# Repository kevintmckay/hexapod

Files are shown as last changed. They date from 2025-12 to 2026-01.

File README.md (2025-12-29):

# Hexapod Robot

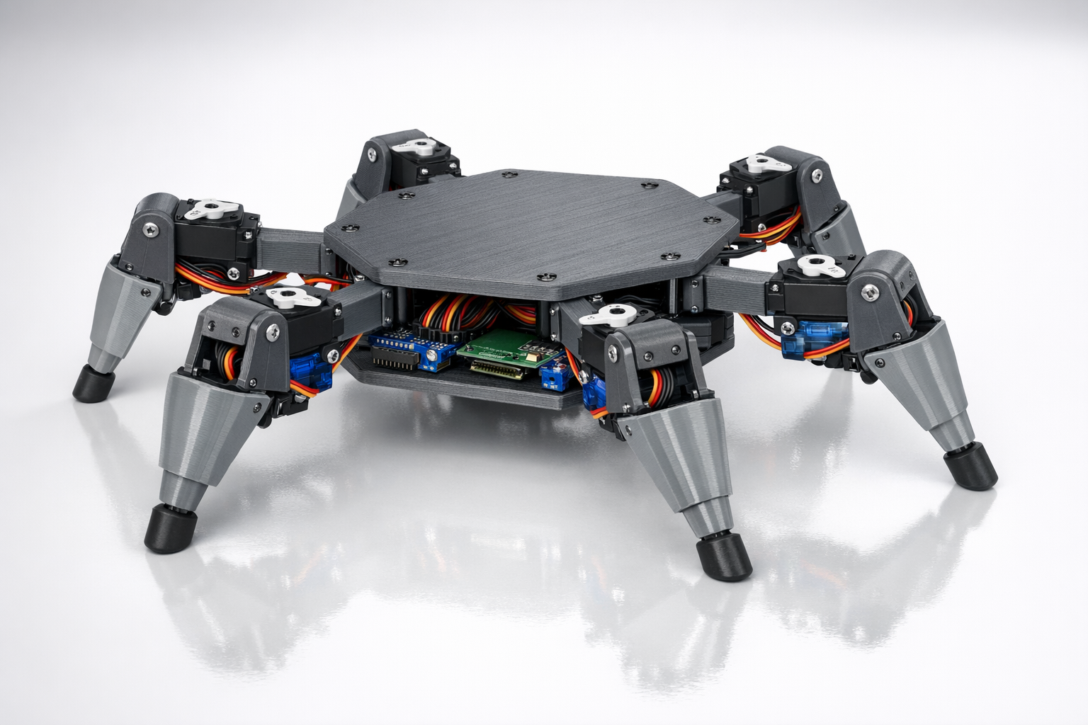
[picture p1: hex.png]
Hexapod Robot


A 3DOF hexapod walking robot with 18 servos, 3D-printed frame, and Python control software.

## Specifications

| Spec | Value |
|---|---|
| Legs | 6 |
| DOF per leg | 3 (coxa, femur, tibia) |
| Total servos | 18 |
| Body size | ~200-250mm across |
| Leg reach | ~150mm from body center |
| Gait types | Tripod, wave, ripple |

## Hardware

- **18x Tower Pro SG90** - All joints (1.8 kg-cm torque, 9g each)
- **2x PCA9685** - 16-channel PWM drivers (I2C)
- **Raspberry Pi Zero 2W** or **Pi Pico** - Main controller
- **3S Li-Ion battery** - 11.1V, 3.5Ah
- **5V BEC** - Servo power distribution

## Leg Geometry

```
     FRONT
  L1       R1
    \     /
     \   /
  L2--[B]--R2
     /   \
    /     \
  L3       R3
     REAR
```

Each leg has 3 joints:
- **Coxa** (25mm) - Hip rotation (horizontal)
- **Femur** (55mm) - Upper leg lift (vertical)
- **Tibia** (75mm) - Lower leg extension (vertical)

## Project Structure

```
hexapod/
├── hex/
│   ├── cad/              # OpenSCAD parametric designs
│   │   ├── leg.scad      # Leg components
│   │   └── test_leg.scad # Test assembly
│   ├── src/              # Python control software
│   │   ├── hexapod.py    # Main controller + IK
│   │   ├── gait.py       # Gait patterns
│   │   ├── pca9685.py    # PWM driver
│   │   └── calibrate.py  # Servo calibration
│   └── PLAN.md           # Detailed project plan
├── HARDWARE              # Bill of materials
└── PRINT_QUEUE.md        # 3D print tracking
```

## Features

- **Inverse Kinematics** - Converts foot position (x, y, z) to servo angles
- **Multiple Gaits** - Tripod (fast), wave (stable), ripple (smooth)
- **Servo Calibration** - Per-servo min/max/center adjustment
- **Simulation Mode** - Test without hardware
- **Dual PCA9685 Support** - 32 PWM channels via I2C

## Getting Started

1. Print the leg components from `hex/cad/`
2. Wire servos to PCA9685 boards per the channel mapping in `hex/PLAN.md`
3. Install dependencies:
   ```bash
   pip install adafruit-circuitpython-pca9685
   ```
4. Run calibration:
   ```bash
   python hex/src/calibrate.py
   ```
5. Test with simulation:
   ```bash
   python hex/src/hexapod.py --simulate
   ```

## License

MIT

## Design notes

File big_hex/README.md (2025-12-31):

# Big Hex - Large Hexapod Robot

Big Hex Render

A larger hexapod build using LX-16A serial bus servos for improved torque, feedback, and simplified wiring.

## Why LX-16A Servos?

| Feature | SG90 (small hex) | LX-16A (big hex) |
|---|---|---|
| Torque | 1.8 kg-cm | 17 kg-cm |
| Control | PWM | Serial Bus |
| Feedback | None | Position, Temp |
| Wiring | 18 separate cables | Daisy-chain per leg |
| Resolution | ~1° | 0.24° |
| Price | ~$2 | ~$15 |

## Specifications

| Spec | Value |
|---|---|
| Legs | 6 |
| DOF per leg | 3 (coxa, femur, tibia) |
| Total servos | 18x LX-16A |
| Body size | ~350mm across |
| Leg reach | ~250mm from body center |
| Target weight | ~2.4kg |
| Payload capacity | ~500g |
| Torque margin | 55% |

## Servo Details

**LewanSoul/Hiwonder LX-16A**
- Torque: 17 kg-cm (6V) / 19.5 kg-cm (7.4V)
- Speed: 0.18s/60° (adjustable)
- Voltage: 6-7.4V
- Size: 40 x 20 x 40.5mm
- Weight: 57g
- Gear: Full metal
- Protocol: TTL Serial (half-duplex)
- Daisy-chain: Yes (up to 253 servos)
- Feedback: Position, temperature, voltage, load

## Cost Estimate

| Part | Qty | Unit Price | Total |
|---|-----|---|---|
| LX-16A servo | 18 | $15 | $270 |
| Servo controller board | 1 | $15 | $15 |
| 2S LiPo 7.4V 3000mAh | 1 | $25 | $25 |
| Raspberry Pi Zero 2W | 1 | $15 | $15 |
| Buck converter 6V 10A | 1 | $10 | $10 |
| 3D printed frame | - | ~$20 filament | $20 |
| Hardware (M3 screws, etc) | - | $15 | $15 |
| **Total** | | | **~$370** |

## Wiring Advantage

### PWM Servos (old way)
```
Pi --> PCA9685 #1 --> 12 separate servo cables
  `--> PCA9685 #2 --> 6 separate servo cables
```
- 18 individual 3-wire cables
- Cable management nightmare
- No feedback

### Serial Bus (LX-16A)
```
Pi (UART) --> L1_coxa --> L1_femur --> L1_tibia
          `-> L2_coxa --> L2_femur --> L2_tibia
          `-> L3_coxa --> L3_femur --> L3_tibia
          `-> R1_coxa --> R1_femur --> R1_tibia
          `-> R2_coxa --> R2_femur --> R2_tibia
          `-> R3_coxa --> R3_femur --> R3_tibia
```
- 6 daisy-chains (one per leg)
- Clean wiring through leg segments
- Full feedback on every servo

## Leg Dimensions

| Segment | Length | Notes |
|---|---|---|
| Coxa | 50mm | Hip rotation |
| Femur | 80mm | Upper leg (optimized for torque) |
| Tibia | 120mm | Lower leg (optimized for torque) |
| **Total reach** | **~250mm** | From body center |

## Links

- [LX-16A on Amazon](https://www.amazon.com/LewanSoul-Real-Time-Feedback-Position-Temperature/dp/B073WR3SK9)
- [Hiwonder LX-16A](https://www.hiwonder.com/products/lx-16a)
- [Arduino Library](https://github.com/madhephaestus/lx16a-servo)
- [Python Library](https://github.com/maximkulkin/lewansoul-lx16a)
- [User Manual PDF](https://cdn.robotshop.com/rbm/a5e9ab51-86bc-497b-adac-003de3088fb7/9/92896585-5e83-4c7c-a663-650b81e5978b/67e9729b_lx-16a-serial-bus-servo-user-manual.pdf)

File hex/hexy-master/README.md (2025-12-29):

# TABLE OF CONTENTS
- Links
- Stuff to Buy and Assemble
- - Electronic Hardware Stuff
- - Frame 
- - Connect Stuff and Calibrate Servos
- Forks by Others
- Configuration and Calibration 
- Sample Usage

#  LINKS
- [Hexy Documentation](http://hexyrobot.wordpress.com)
- [Hexy Transcript](https://medium.com/@mithi/a-raspberry-pi-hexy-transcript-62533c69a566)

# STUFF TO BUY AND ASSEMBLE

## Electronic Hardware stuff 
I bought a bunch of stuff, here are the most important stuff:
- [Two Adafruit 16-channel PWM servo drivers](https://learn.adafruit.com/16-channel-pwm-servo-driver)
- [A Raspberry Pi Zero](https://www.adafruit.com/product/3400)
- [Nineteen DFRobot 9g metal gear servos (1.8kg torque)](https://www.dfrobot.com/product-1338.html)
- [5V, 10A power supply](https://www.adafruit.com/product/658)
- [All other stuff outlined here](https://hexyrobot.wordpress.com/2016/02/08/hexy-modifications/) 

## Frame
The screws and nuts are the 3M ones you can buy from your local hardware store. You can lazer cut or 3D print 
Arcbotic's Hexapod frame as they have open-sources the files in DXF and STL format. I used a 5mm acrylic sheet. 
- [Arcbotics Frame](https://github.com/arcbotics/hexy)
- [Arcbotics Frame Build Instructions](http://arcbotics.com/products/hexy/start/)

## Connect Stuff and Calibrate Servos
Adafruit has good tutorials for how to wire the drivers and all with the Arduino and Raspberry Pi. 
- [Servo Driver with Arduino](https://learn.adafruit.com/16-channel-pwm-servo-driver?view=all)
- [Servo Driver Hat with Raspberry Pi](https://learn.adafruit.com/adafruit-16-channel-pwm-slash-servo-shield?view=all)
- The large Raspberry Pi 2B and 3B has the same 40-pin configuration as the Raspberry Pi Zero, you just follow how to wire the I2C pins there. 
- These tutorials are also good starting point to calibrate the minimum and maximum pulses of each of your servo which you'd have to do. 

# CHECKOUT FORKS BY OTHERS

@robottwo has implemented a nice gui and config file which I haven't merged (or let alone tested), 
you might be interested cloning that instead: 

- [ROBOTTWO'S FORK](https://github.com/robottwo/hexy/tree/config)
> You may have your servo controllers on different addresses, or your servos plugged into different ports. You will also have to calibrate the min and max range of each of your servos, since these settings vary from servo to servo.
These settings are all stored in the hexy.cfg file. To help with this task, there is a GUI program scripts/detect_controllers.py. - ROBOTTWO

# CONFIGURATION AND CALIBRATION

You should take a look at the base file here as it is implemented in a pretty straightforward manner:
- [BASE FILE - CORE.PY](https://github.com/mithi/hexy/blob/master/hexy/robot/core.py)

You may need to edit `lines 4 to 22` of this file (and a bunch of other lines) depending on the configuration of your Hexapod and if you are using a different frame or if you are using different I2C addresses.  

```
""" joint_key convention:
    R - right, L - left
    F - front, M - middle, B - back
    H - hip, K - knee, A - Ankle
    key : (channel, minimum_pulse_length, maximum_pulse_length) """

joint_properties = {

    'LFH': (0, 248, 398), 'LFK': (1, 188, 476), 'LFA': (2, 131, 600),
    'RFH': (3, 275, 425), 'RFK': (4, 227, 507), 'RFA': (5, 160, 625),
    'LMH': (6, 312, 457), 'LMK': (7, 251, 531), 'LMA': (8, 138, 598),
    'RMH': (9, 240, 390), 'RMK': (10, 230, 514), 'RMA': (11, 150, 620),
    'LBH': (12, 315, 465), 'LBK': (13, 166, 466), 'LBA': (14, 140, 620),
    'RBH': (15, 320, 480), 'RBK': (16, 209, 499), 'RBA': (17, 150, 676),
    'N': (18, 150, 650)
}

driver1 = PWM(0x40)
driver2 = PWM(0x41)
```

Or you may need to edit many of the lines in this file. For example this is what @patrickpoirier51 submitted as an issue: 
- https://github.com/mithi/hexy/issues/3

> I do have a different type of hexapod and the servo configuration makes the left and right side asymmetric, so +10 deg on left side makes -10 deg on right side. - @patrickpoirier51

Basically to solve his issue, he added a `direction` or a symmetry parameter at `joint_properties` IE
```
joint_properties = {

    'LFH': (0, 330, 480, -1), 'LFK': (1, 200, 515, -1), 'LFA': (2, 130, 610, 1),
    'RFH': (3, 380, 530, 1), 'RFK': (4, 300, 615, 1), 'RFA': (5, 130, 610, -1),
    'LMH': (6, 320, 470, -1), 'LMK': (7, 251, 531, -1), 'LMA': (8, 130, 610, 1),
    'RMH': (9, 380, 530, 1), 'RMK': (10, 290, 605, 1), 'RMA': (11, 150, 630, -1),
    'LBH': (12, 350, 500, -1), 'LBK': (13, 200, 515, -1), 'LBA': (14, 180, 660, 1),
    'RBH': (15, 350, 500, 1), 'RBK': (16, 300, 615, 1), 'RBA': (17, 130, 610, -1),
    'N': (18, 150, 650, 1)
    
```
And consequently updated the initialization of `Joint` in line `132`
```
    self.channel, self.min_pulse, self.max_pulse, self.direction = joint_properties[jkey]
```

As well as the `pose()` method in `Joint` in line `140`

```
    pulse = remap((angle * self.direction), (-self.max, self.max), (self.min_pulse, self.max_pulse))
```

Also equally important is the range of motion of each `Joint` which I've defined in line `87` of the `Leg` class.
The ankle has a range of motion from `-90 to 90` while the hip and knee's range is `-45, 45` and `-50, 50` respectively. 
I have a  knee leeway of 10 degrees. Change these as you see fit.
```
max_hip, max_knee, knee_leeway = 45, 50, 10
```

# SAMPLE USAGE
```
HexapodCore > Hexapod > HexapodPro > DancingHexapod
```
 
The easiest way to get this up and running, on your raspberry pi zero is to do the following on the terminal via ssh.

## Setup 
```
$ ssh YOUR.RPI.IP.ADDR -l pi 
$ cd /home/pi
$ git clone https://github.com/mithi/hexy.git
$ sudo python setup.py install
$ python -m hexy.demo.demo1
$ python -m hexy.demo.demo2
$ python -m hexy.demo.demo3
```

## High Level Usage

Sample usage when running python interpreter from anywhere in your system... 

```
>>> from hexy.robot.hexapod import Hexapod
>>> hexy = Hexapod()
>>> hexy.boot_up()
>>> hexy.walk(swing = 25, repetitions = 10)
>>> hexy.walk(swing = -25, repetitions = 10)
>>> hexy.rotate(offset = 40, repetitions = 7)
>>> hexy.rotate(offset = -40, repetitions = 7)
>>> hexy.shut_down()
```

Also try this...

```
>>> from hexy.robot.pro import HexapodPro
>>> hexy = HexapodPro()
>>> hexy.lie_flat()
>>> hexy.get_up()
>>> hexy.shake_head()
>>> hexy.wave()
>>> hexy.point()
>>> hexy.type_stuff()
>>> hexy.lie_down()
>>> hexy.off()
```

And this :)

```
>>> from hexy.robot.dancing import DancingHexapod
>>> hexy = DancingHexapod()
>>> hexy.boot_up()
>>> hexy.night_fever()
>>> hexy.default()
>>> hexy.dance_tilt()
>>> hexy.squat(angle = 60)
>>> hexy.thriller()
>>> hexy.lie_down()
>>> hexy.curl_up(die = True)
```

## Low Level Usage

If you want to control the angle of each `Joint` (`hip`, `knee`, `ankle`) for each `Leg` you'd want to instantiate a `HexapodCore` object:

```
>>> from hexy.robot.core import HexapodCore
>>> hexy = HexapodCore()
```

Each `Leg` can be access like this which is based in its position:

```
hexy.left_front
hexy.left_middle
hexy.left_back
 
hexy.right_front
hexy.right_middle
hexy.right_back
 
```

Whose three `Joints` you can individual pose using the `pose` command, for example:

```
hexy.right_front.pose(hip_angle = 0, knee_angle = 0, ankle_angle = 0)
hexy.right_front.off() # prevents servo overloading
```

There are also built-in lists of legs which you can iterate over:

```
hexy.legs # all six legs
hexy.right_legs 
hexy.left_legs
hexy.tripod1 # left front, right middle left back
hexy.tripod2 # right front, left middle, right back
```

For example:

```
for leg in hexy.right_legs:
  leg.hip.pose(angle = 0)
  leg.knee.pose(angle = 0)
  leg.ankle.pose(angle = 0)
  leg.off()

for leg in hexy.tripod1:
  leg.knee.pose(angle = 0)
  leg.knee.off()
```

You can also pose the `neck`:
```
hexy.neck.pose(angle = 90)
hexy.neck.off()
```

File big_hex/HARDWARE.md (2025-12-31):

# Big Hex Hardware List

## Servos

| Part | Qty | Specs | Price | Link |
|---|-----|---|---|---|
| LX-16A Serial Bus Servo | 18 | 17kg-cm, 7.4V, metal gear | ~$15 ea | [Amazon](https://www.amazon.com/LewanSoul-Real-Time-Feedback-Position-Temperature/dp/B073WR3SK9) |

### LX-16A Specifications
```
Torque:       17 kg-cm (6V) / 19.5 kg-cm (7.4V)
Speed:        0.18 sec/60° (adjustable via software)
Voltage:      6V - 7.4V DC
Angle:        0-240° (configurable)
Resolution:   0.24°
Size:         45 x 25 x 36mm (verified)
Weight:       52-57g
Gears:        Full metal
Bearings:     Dual ball bearing
Protocol:     TTL Serial (half-duplex, 115200 baud default)
Feedback:     Position, temperature, voltage, load
```

## Controller

| Part | Qty | Notes | Price |
|---|-----|---|---|
| Raspberry Pi Zero 2W | 1 | Main controller, UART for servos | $15 |
| LX-16A Debug Board | 1 | Optional - for servo configuration | $10 |

### Alternative Controllers
- Raspberry Pi 4 (more power, WiFi)
- ESP32 (cheaper, MicroPython)
- Arduino Mega + TTL level shifter

## Power

| Part | Qty | Specs | Price |
|---|-----|---|---|
| 2S LiPo Battery | 1 | 7.4V, 3000-5000mAh, 25C+ | $25-40 |
| Buck Converter | 1 | Input 7.4V, Output 6V 10A | $10 |
| Power switch | 1 | 10A rated | $3 |
| XT60 connectors | 2 | Battery connection | $5 |

### Power Budget
```
18 servos × 1A peak = 18A peak (worst case, all stalled)
18 servos × 0.3A avg = 5.4A typical draw
3000mAh battery = ~30 min runtime (estimate)
5000mAh battery = ~50 min runtime (estimate)
```

## Frame (3D Printed)

### Option A: Segmented Body (standard printers ~220mm bed)
| Part | Qty | Material | Est. Print Time |
|---|-----|---|---|
| Body plate segment (top) | 6 | PETG | 1.5h each |
| Body plate segment (bottom) | 6 | PETG | 1.5h each |
| Coxa bracket | 6 | PETG | 45min each |
| Femur link (80mm) | 6 | PETG | 40min each |
| Tibia link (120mm) | 6 | PETG | 30min each |
| Foot tip | 6 | TPU | 10min each |
| Standoff (45mm) | 12 | PETG | 5min each |
| **Total** | | | **~25h** |

### Option B: Full Body (large printers ~300mm+ bed)
| Part | Qty | Material | Est. Print Time |
|---|-----|---|---|
| Body plate (top) | 1 | PETG | 4h |
| Body plate (bottom) | 1 | PETG | 4h |
| Coxa bracket | 6 | PETG | 45min each |
| Femur link (80mm) | 6 | PETG | 40min each |
| Tibia link (120mm) | 6 | PETG | 30min each |
| Foot tip | 6 | TPU | 10min each |
| Standoff (45mm) | 12 | PETG | 5min each |
| **Total** | | | **~20h** |

### Print Settings
- Material: PETG (stronger than PLA)
- Layer height: 0.2mm
- Infill: 40% (structural parts)
- Walls: 4
- Supports: Yes (for servo pockets)
- Body segments: bolt together with M3x12 screws

## Hardware

| Part | Qty | Notes |
|---|-----|---|
| M3 x 8mm screws | 50 | Servo mounting |
| M3 x 12mm screws | 30 | Frame assembly |
| M3 nuts | 50 | |
| M3 lock nuts | 20 | Joints |
| M3 washers | 50 | |
| Servo horn screws | 18 | Included with servos |
| Standoffs (3D printed) | 12 | Body plate spacing (45mm) |
| Zip ties | 50 | Cable management |
| Heat shrink | - | Wire connections |

## Wiring

| Part | Qty | Notes |
|---|-----|---|
| 18AWG silicone wire (red) | 2m | Power distribution |
| 18AWG silicone wire (black) | 2m | Ground |
| 22AWG servo wire | 3m | Signal extension |
| JST-XH connectors | 20 | Servo connections |
| Dupont connectors | 20 | Pi connections |

## Tools Needed

- Soldering iron + solder
- Wire strippers
- Crimping tool (for JST/Dupont)
- Hex drivers (M2, M2.5, M3)
- 3D printer (or printing service)
- Multimeter

## Total Cost Estimate

| Category | Cost |
|---|---|
| Servos (18x LX-16A) | $270 |
| Controller | $15 |
| Power system | $40 |
| 3D printing | $20 |
| Hardware | $15 |
| Wiring | $10 |
| **Total** | **~$370** |

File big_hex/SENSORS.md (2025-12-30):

# Big Hex Sensor Array

Simple but complete sensor setup for autonomous walking.

## Overview

| Sensor | Purpose | Qty | Price | Total |
|---|---|-----|---|---|
| MPU6050 | IMU (balance/tilt) | 1 | $3 | $3 |
| VL53L0X | ToF distance (obstacles) | 3 | $5 | $15 |
| Limit switch | Foot contact | 6 | $0.50 | $3 |
| INA219 | Power monitor | 1 | $4 | $4 |
| **Total** | | **11** | | **~$25** |

## Sensor Details

### 1. MPU6050 - Balance/Orientation

```
Type:       6-axis IMU (3-axis gyro + 3-axis accel)
Interface:  I2C (0x68)
Voltage:    3.3V
Size:       20 x 16mm
Price:      ~$3
```

**Capabilities:**
- Pitch, roll, yaw detection
- Angular velocity (gyro): ±250 to ±2000°/s
- Acceleration: ±2g to ±16g
- Built-in DMP for sensor fusion

**Use cases:**
- Detect slopes and adjust gait
- Fall detection and recovery
- Level body on uneven terrain
- Smooth motion filtering

### 2. VL53L0X - Distance Sensing (×3)

```
Type:       Time-of-Flight laser ranging
Interface:  I2C (0x29, configurable)
Range:      30mm - 2000mm
Accuracy:   ±3%
Voltage:    2.8-5V
Size:       13 x 18mm
Price:      ~$5 each
```

**Placement:**
```
            FRONT
              │
     VL53L0X  │  VL53L0X
      (L)     │    (R)
        \     │     /
         \    │    /
          ┌───┴───┐
          │VL53L0X│  (center, angled 30° down)
          │ BODY  │
          └───────┘
```

**Use cases:**
- Obstacle detection (walls, objects)
- Drop-off/cliff detection (stairs, edges)
- Distance to objects for navigation
- Front-facing coverage ~120°

**I2C Address Setup:**
Each VL53L0X defaults to 0x29. To use multiple:
1. Hold XSHUT low on all but one
2. Set new address via software
3. Release next XSHUT, repeat

```
Sensor    XSHUT Pin    Address
------    ---------    -------
Center    GPIO 17      0x29
Left      GPIO 27      0x30
Right     GPIO 22      0x31
```

### 3. Foot Contact Switches (×6)

```
Type:       Micro limit switch (lever arm)
Interface:  Digital GPIO (pulled up)
Voltage:    3.3V logic
Size:       20 x 10mm
Price:      ~$0.50 each
```

**Wiring:**
```
3.3V ─────┐
          │
     ┌────┴────┐
     │  Switch │
     └────┬────┘
          │
GPIO ─────┼───── 10kΩ ───── GND
     (INPUT_PULLUP)
```

**GPIO Assignment:**
```
Foot    GPIO Pin
----    --------
L1      GPIO 5
L2      GPIO 6
L3      GPIO 13
R1      GPIO 19
R2      GPIO 26
R3      GPIO 12
```

**Use cases:**
- Detect ground contact during step
- Adaptive gait timing
- Terrain irregularity sensing
- Step confirmation before weight transfer

**Alternative: Use LX-16A Load Feedback**
The LX-16A servos report load/torque. A spike in tibia servo load indicates ground contact - can supplement or replace physical switches.

### 4. INA219 - Power Monitor

```
Type:       Current/voltage/power sensor
Interface:  I2C (0x40)
Voltage:    3-5.5V
Current:    Up to 3.2A (±0.8mA resolution)
Size:       25 x 25mm
Price:      ~$4
```

**Wiring:**
```
Battery + ──► INA219 VIN+ ──► INA219 VIN- ──► Load (BEC)
```

**Use cases:**
- Battery voltage monitoring (low battery warning)
- Current draw measurement
- Power consumption logging
- Stall detection (current spike)

## Wiring Diagram

```
┌─────────────────────────────────────────────────────────────────┐
│                      Pi Zero 2W GPIO                            │
├─────────────────────────────────────────────────────────────────┤
│                                                                 │
│   3.3V (Pin 1)  ───┬──► MPU6050 VCC                             │
│                    ├──► VL53L0X VCC (×3)                        │
│                    ├──► INA219 VCC                              │
│                    └──► Pull-up resistors                       │
│                                                                 │
│   GND (Pin 6)   ───┬──► All sensor GND                          │
│                    └──► Switch common                           │
│                                                                 │
│   SDA (GPIO 2)  ───────► I2C Data bus ──┬── MPU6050             │
│                                         ├── VL53L0X (×3)        │
│                                         └── INA219              │
│                                                                 │
│   SCL (GPIO 3)  ───────► I2C Clock bus ─┴── (all I2C devices)   │
│                                                                 │
│   GPIO 17 ─────────────► VL53L0X Center XSHUT                   │
│   GPIO 27 ─────────────► VL53L0X Left XSHUT                     │
│   GPIO 22 ─────────────► VL53L0X Right XSHUT                    │
│                                                                 │
│   GPIO 5  ─────────────► Foot Switch L1                         │
│   GPIO 6  ─────────────► Foot Switch L2                         │
│   GPIO 13 ─────────────► Foot Switch L3                         │
│   GPIO 19 ─────────────► Foot Switch R1                         │
│   GPIO 26 ─────────────► Foot Switch R2                         │
│   GPIO 12 ─────────────► Foot Switch R3                         │
│                                                                 │
│   TX (GPIO 14) ────────► LX-16A Serial Bus (servos)             │
│   RX (GPIO 15) ◄─────── LX-16A Serial Bus                       │
│                                                                 │
└─────────────────────────────────────────────────────────────────┘
```

## I2C Address Map

```
Address    Device
-------    ------
0x29       VL53L0X Center (default)
0x30       VL53L0X Left (configured)
0x31       VL53L0X Right (configured)
0x44       INA219 (A0 jumper soldered - see note below)
0x68       MPU6050
```

**IMPORTANT - INA219 Address Conflict:**
The INA219 defaults to address 0x40, which conflicts with PCA9685 #1 (servo driver).
To avoid this conflict, solder the A0 jumper on the INA219 board to change its address to 0x44.

INA219 address options:
- 0x40: A0=GND, A1=GND (default - conflicts with PCA9685!)
- 0x41: A0=VS+, A1=GND (conflicts with PCA9685 #2)
- 0x44: A0=GND, A1=VS+ (recommended)
- 0x45: A0=VS+, A1=VS+

When initializing the INA219 in Python:
```python
ina = adafruit_ina219.INA219(i2c, addr=0x44)
```

## Software Libraries

### Python (Raspberry Pi)

```bash
# Install libraries
pip install adafruit-circuitpython-mpu6050
pip install adafruit-circuitpython-vl53l0x
pip install adafruit-circuitpython-ina219
pip install RPi.GPIO
```

### Basic Usage

```python
import board
import busio
import adafruit_mpu6050
import adafruit_vl53l0x
import adafruit_ina219
import RPi.GPIO as GPIO

# I2C bus
i2c = busio.I2C(board.SCL, board.SDA)

# IMU
mpu = adafruit_mpu6050.MPU6050(i2c)
print(f"Accel: {mpu.acceleration}")
print(f"Gyro: {mpu.gyro}")

# Distance sensor
vl53 = adafruit_vl53l0x.VL53L0X(i2c)
print(f"Distance: {vl53.range}mm")

# Power monitor
ina = adafruit_ina219.INA219(i2c)
print(f"Voltage: {ina.bus_voltage}V")
print(f"Current: {ina.current}mA")

# Foot switches
GPIO.setmode(GPIO.BCM)
FOOT_PINS = [5, 6, 13, 19, 26, 12]
for pin in FOOT_PINS:
    GPIO.setup(pin, GPIO.IN, pull_up_down=GPIO.PUD_UP)

def foot_contact(leg):
    return not GPIO.input(FOOT_PINS[leg])
```

## Sensor Fusion Strategy

```
┌─────────────────────────────────────────────────────────────┐
│                    SENSOR FUSION                            │
├─────────────────────────────────────────────────────────────┤
│                                                             │
│   MPU6050 ──► Body tilt ──► Adjust leg heights              │
│                         └──► Detect falling ──► Recovery    │
│                                                             │
│   VL53L0X ──► Obstacle ahead ──► Stop/turn                  │
│          └──► Drop detected ──► Don't step there            │
│                                                             │
│   Foot SW ──► Ground contact ──► Transfer weight            │
│          └──► No contact ──► Extend leg further             │
│                                                             │
│   INA219 ──► Low voltage ──► Return to base / warn user     │
│          └──► High current ──► Reduce speed / check stall   │
│                                                             │
│   LX-16A ──► Servo load ──► Supplement foot contact         │
│   (built-in) Position ──► Verify movement completed         │
│                                                             │
└─────────────────────────────────────────────────────────────┘
```

## Parts List (with links)

| Part | Link | Price |
|---|---|---|
| MPU6050 | [Amazon](https://www.amazon.com/HiLetgo-MPU-6050-Accelerometer-Gyroscope-Converter/dp/B00LP25V1A) | $3 |
| VL53L0X (3-pack) | [Amazon](https://www.amazon.com/HiLetgo-VL53L0X-Distance-Measurement-Breakout/dp/B071DW8M8V) | $12 |
| Micro Limit Switch (10-pack) | [Amazon](https://www.amazon.com/Cylewet-Switch-Action-Arduino-CYT1073/dp/B07DQKZBQV) | $6 |
| INA219 | [Amazon](https://www.amazon.com/HiLetgo-INA219-Bi-direction-Current-Breakout/dp/B01DUVKZC4) | $4 |

## Optional Upgrades

| Sensor | Purpose | Price | Notes |
|---|---|---|---|
| BNO055 | 9-axis IMU + fusion | $25 | Better than MPU6050, built-in AHRS |
| VL53L1X | Longer range ToF | $12 | 4m range vs 2m |
| FSR402 | Analog foot pressure | $5 ea | Measure force, not just contact |
| BME280 | Environment | $5 | Temp, humidity, pressure |
| Pi Camera v2 | Vision | $25 | Object detection, SLAM |
| RPLidar A1 | 360° mapping | $100 | Full room mapping |

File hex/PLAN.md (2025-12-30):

# Hexapod Robot Project

## Overview

3DOF hexapod walker using existing servo inventory and 3D printed frame.

## Specifications

| Spec | Value |
|---|---|
| Legs | 6 |
| DOF per leg | 3 (coxa, femur, tibia) |
| Total servos | 18 |
| Gait types | Tripod, wave, ripple |
| Target size | ~250mm body, ~150mm leg reach |

## Parts Allocation

### From Inventory

| Part | Qty | Use | Notes |
|---|-----|-----|---|
| Tower Pro SG90 | 18 | All joints (coxa, femur, tibia) | 1.8 kg-cm torque, keep robot lightweight |
| PCA9685 | 2 | PWM control | 16ch each = 32ch total (18 needed) |
| SpeedyBee F405 or Arduino | 1 | Main controller | Or use Pi Zero/Pi Pico |
| 3S Li-Ion (Titan) | 1 | Power | 11.1V, 3.5Ah - good runtime |
| FTDI adapter | 1 | Programming/debug | |

### To Purchase

| Part | Est. Cost | Notes |
|---|---|---|
| Pi Pico or Pi Zero 2W | $5-15 | Recommended controller |
| Buck converter 5V/5A | $5-10 | Servo power (BEC) |
| Servo wire extensions | $5 | 15-20cm leads |
| M2/M2.5 hardware kit | $10 | Servo mounting screws |
| **Total** | ~$25-40 | |

### To 3D Print

| Part | Qty | Material | Notes |
|---|-----|---|---|
| Body plate (top) | 1 | PLA/PETG | Hex shape, ~200mm across |
| Body plate (bottom) | 1 | PLA/PETG | Electronics mount |
| Coxa bracket | 6 | PLA/PETG | Hip rotation mount |
| Femur link | 6 | PLA/PETG | Upper leg, ~60mm |
| Tibia link | 6 | PLA/PETG | Lower leg, ~80mm |
| Foot tip | 6 | TPU | Rubber for grip (optional) |
| Servo horn adapters | 18 | PLA | If needed for fit |

## Leg Geometry

```
        [BODY]
           |
      +---------+
      |  COXA   |  <- SG90 (horizontal rotation)
      +---------+
           |
      +---------+
      |  FEMUR  |  <- SG90 (vertical lift)
      +---------+
           |
      +---------+
      |  TIBIA  |  <- SG90 (vertical extend)
      +---------+
           |
         [FOOT]
```

## Wiring Plan

### Power Distribution

```
3S Li-Ion (11.1V)
    |
    +---> Buck Converter ---> 5V rail
              |
              +---> PCA9685 #1 V+ (servos 0-11)
              +---> PCA9685 #2 V+ (servos 12-17)
              +---> Controller (Pi Pico 5V or VSYS)
```

### I2C Bus

```
Controller (Pi Pico / Pi Zero)
    |
    +-- SDA (GPIO 2) ----+---- PCA9685 #1 (0x40)
    |                    |
    +-- SCL (GPIO 3) ----+---- PCA9685 #2 (0x41) <- solder A0 jumper
```

### Servo Channel Mapping

| PCA9685 | Ch | Leg | Joint |
|---|-----|-----|---|
| #1 | 0 | L1 | Coxa |
| #1 | 1 | L1 | Femur |
| #1 | 2 | L1 | Tibia |
| #1 | 3 | L2 | Coxa |
| #1 | 4 | L2 | Femur |
| #1 | 5 | L2 | Tibia |
| #1 | 6 | L3 | Coxa |
| #1 | 7 | L3 | Femur |
| #1 | 8 | L3 | Tibia |
| #1 | 9 | R1 | Coxa |
| #1 | 10 | R1 | Femur |
| #1 | 11 | R1 | Tibia |
| #2 | 0 | R2 | Coxa |
| #2 | 1 | R2 | Femur |
| #2 | 2 | R2 | Tibia |
| #2 | 3 | R3 | Coxa |
| #2 | 4 | R3 | Femur |
| #2 | 5 | R3 | Tibia |

### Leg Numbering (top view)

```
     FRONT
  L1       R1
    \     /
     \   /
  L2--[B]--R2
     /   \
    /     \
  L3       R3
     REAR
```

## Software Architecture

### Option A: Pi Pico (MicroPython)

```
main.py
├── hexapod.py      # Leg kinematics, gait engine
├── servo.py        # PCA9685 wrapper
├── gait.py         # Tripod, wave, ripple patterns
└── remote.py       # Bluetooth/serial control
```

### Option B: Pi Zero 2W (Python + ROS2)

```
hex_ws/src/
├── hex_control/        # Servo control node
├── hex_kinematics/     # IK solver
├── hex_gait/           # Gait generator
└── hex_teleop/         # Joystick/keyboard control
```

### Inverse Kinematics

Each leg needs IK to convert (x, y, z) foot position to servo angles:

```python
def leg_ik(x, y, z, coxa_len, femur_len, tibia_len):
    """
    x: forward/back from coxa
    y: left/right from coxa
    z: up/down from coxa
    Returns: (coxa_angle, femur_angle, tibia_angle) in degrees
    """
    # Coxa angle (top-down rotation)
    coxa_angle = atan2(y, x)

    # Distance in XY plane
    xy_dist = sqrt(x**2 + y**2) - coxa_len

    # Distance to foot
    foot_dist = sqrt(xy_dist**2 + z**2)

    # Femur and tibia angles (2-link planar IK)
    # Law of cosines
    cos_tibia = (femur_len**2 + tibia_len**2 - foot_dist**2) / (2 * femur_len * tibia_len)
    tibia_angle = acos(clamp(cos_tibia, -1, 1))

    cos_femur = (femur_len**2 + foot_dist**2 - tibia_len**2) / (2 * femur_len * foot_dist)
    femur_angle = atan2(z, xy_dist) + acos(clamp(cos_femur, -1, 1))

    return degrees(coxa_angle), degrees(femur_angle), degrees(tibia_angle)
```

## Build Phases

### Phase 1: Design and Print
- [ ] Design body plates in CAD (Fusion 360 / OpenSCAD)
- [ ] Design leg segments with servo pockets
- [ ] Print test leg (1x) to verify fit
- [ ] Print remaining parts

### Phase 2: Electronics
- [ ] Test PCA9685 with single servo
- [ ] Set second PCA9685 to address 0x41
- [ ] Wire power distribution
- [ ] Test all 18 servos individually

### Phase 3: Assembly
- [ ] Mount servos in printed brackets
- [ ] Assemble one leg completely
- [ ] Verify range of motion
- [ ] Assemble remaining legs
- [ ] Mount electronics in body

### Phase 4: Software
- [ ] Servo calibration (center positions)
- [ ] Single leg IK test
- [ ] Standing pose (all legs)
- [ ] Basic tripod gait
- [ ] Remote control integration

### Phase 5: Refinement
- [ ] Tune gait parameters
- [ ] Add wave/ripple gaits
- [ ] Battery monitoring
- [ ] Optional: IMU for balance

## Reference Dimensions

Based on SG90 servo size (all 18 servos):

| Servo | Size (mm) | Weight | Torque |
|---|---|---|---|
| SG90 | 23 x 12 x 29 | 9g | 1.8 kg-cm |

Suggested link lengths:
- Coxa: 25mm (short, just clears body)
- Femur: 50-60mm
- Tibia: 70-80mm
- Total reach: ~150mm from body center

## Resources

- Inverse Kinematics: https://oscarliang.com/inverse-kinematics-implementation-hexapod-robots/
- PCA9685 library: adafruit-circuitpython-pca9685
- Gait patterns: https://www.robotshop.com/community/blog/show/hexapod-robot-gait-simulation

---

*Created: 2025-12-28*

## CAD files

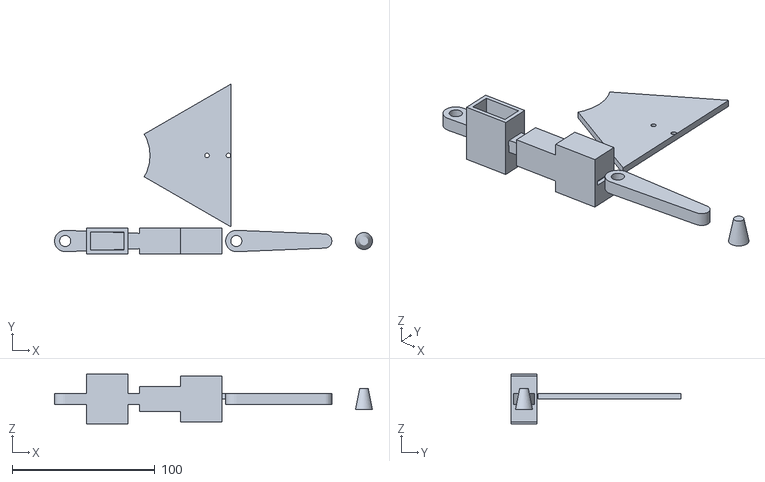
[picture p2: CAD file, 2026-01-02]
hex/cad/stl/tibia_link.stl
223.0 x 119.0 x 35.0

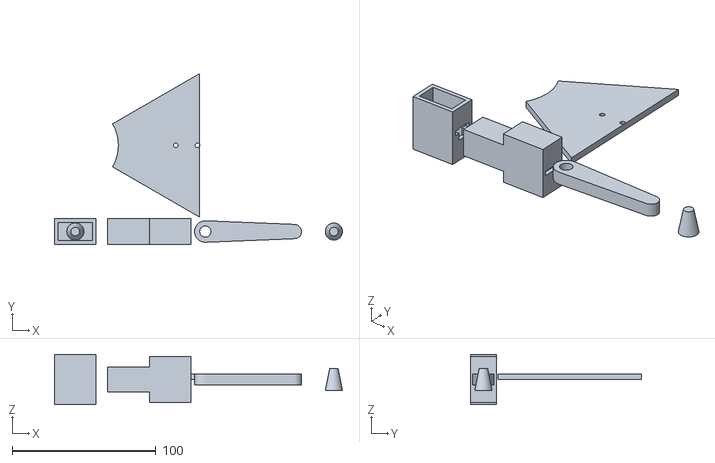
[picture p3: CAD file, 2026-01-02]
hex/cad/stl/foot_tip.stl
200.5 x 119.0 x 35.0

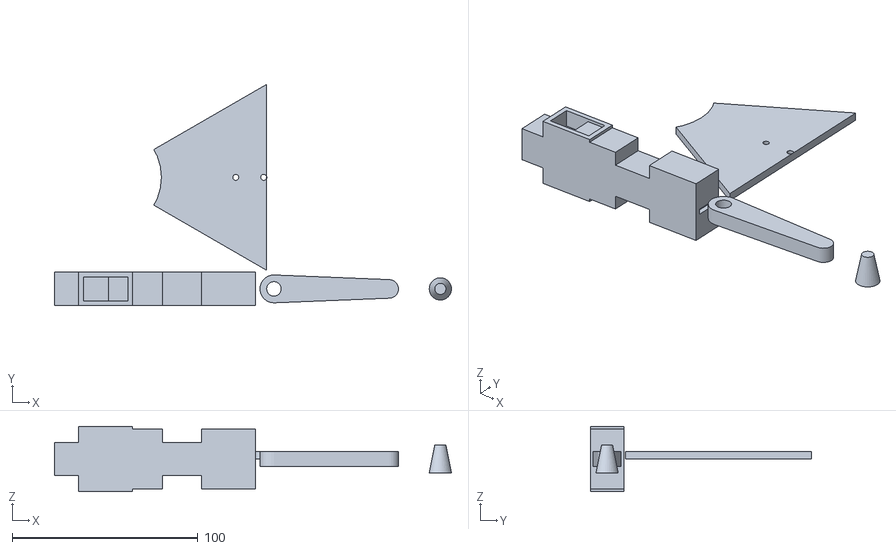
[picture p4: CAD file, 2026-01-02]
hex/cad/stl/femur_link.stl
213.5 x 119.0 x 35.0

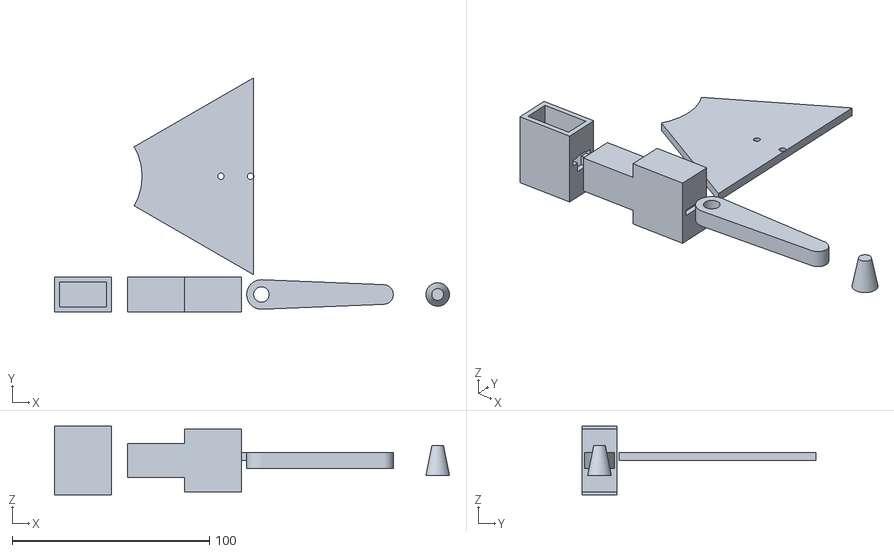
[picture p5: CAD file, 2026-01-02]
hex/cad/stl/coxa_bracket.stl
200.5 x 119.0 x 35.0

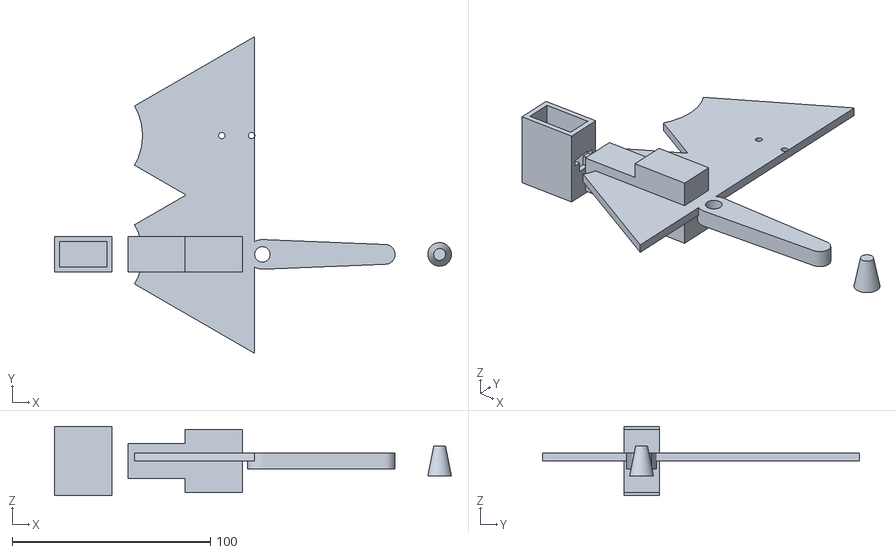
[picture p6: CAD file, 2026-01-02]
hex/cad/stl/body_segment.stl
200.5 x 160.0 x 35.0

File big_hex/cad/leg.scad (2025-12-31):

// Big Hex - Large Hexapod Leg Design
// For LX-16A Serial Bus Servos (45 x 25 x 36mm) - CORRECTED
// Body: 350mm across, Leg reach: ~250mm
// Torque margin: 55% with 80mm femur + 120mm tibia

/* [LX-16A Servo Dimensions] */
// CORRECTED dimensions from datasheet (was 40x20x40.5)
lx16a_length = 45;      // Along shaft axis (verified)
lx16a_width = 25;       // Side to side (verified)
lx16a_height = 36;      // Top to bottom (verified)
lx16a_shaft_offset = 9; // Shaft center from edge
lx16a_shaft_dia = 6;
lx16a_horn_dia = 25;    // Standard horn diameter
lx16a_mount_hole_spacing = 52;  // Between mounting tabs (updated)
lx16a_mount_hole_dia = 3.2;     // M3 clearance holes
lx16a_tab_width = 8;
lx16a_tab_thickness = 2.5;

/* [Leg Dimensions] */
coxa_length = 50;       // Hip segment
femur_length = 80;      // Upper leg (was 100, reduced for torque margin)
tibia_length = 120;     // Lower leg (was 150, reduced for torque margin)
wall_thickness = 4;     // Structural walls
clearance = 0.4;        // Printer tolerance (increased slightly)

/* [Body Dimensions] */
body_radius = 175;      // ~350mm across (was 200, reduced for weight)
body_thickness = 5;
standoff_height = 45;   // Between plates (slightly reduced)

/* [Tube Dimensions] */
leg_tube_od = 28;       // Outer diameter of leg tubes (was 25, increased for strength)
leg_tube_id = 22;       // Inner diameter (wire routing)

/* [Rendering] */
$fn = 48;

// ============================================
// LX-16A Servo Pocket (for embedding)
// UPDATED: Corrected dimensions and added mounting holes
// ============================================
module lx16a_pocket() {
    c = clearance;

    union() {
        // Main body - corrected size
        cube([lx16a_length + c*2, lx16a_width + c*2, lx16a_height + c*2], center=true);

        // Mounting tabs slot - wider for actual servo
        translate([0, 0, lx16a_height/2 - 5])
            cube([lx16a_mount_hole_spacing + 12, lx16a_width + c*2, lx16a_tab_thickness + c*2], center=true);

        // Mounting screw holes through bracket (M3 clearance)
        for (x = [-lx16a_mount_hole_spacing/2, lx16a_mount_hole_spacing/2]) {
            translate([x, 0, lx16a_height/2])
                cylinder(d=lx16a_mount_hole_dia, h=15, center=true);
        }

        // Cable exit - larger for daisy-chain connectors
        translate([0, -lx16a_width/2 - 5, -lx16a_height/4])
            cube([15, 15, 12], center=true);
    }
}

// LX-16A outline for visualization
module lx16a_servo() {
    color("DimGray") {
        // Main body
        cube([lx16a_length, lx16a_width, lx16a_height], center=true);

        // Mounting tabs
        translate([0, 0, lx16a_height/2 - 5])
            cube([lx16a_mount_hole_spacing + lx16a_tab_width, lx16a_width, lx16a_tab_thickness], center=true);

        // Output shaft
        translate([lx16a_length/2 - lx16a_shaft_offset, 0, lx16a_height/2])
            cylinder(d=lx16a_shaft_dia, h=8);
    }
}

// ============================================
// Coxa Bracket - Hip rotation mount
// ============================================
module coxa_bracket() {
    bracket_w = lx16a_width + wall_thickness*2;
    bracket_l = lx16a_length + wall_thickness*2;
    bracket_h = lx16a_height + wall_thickness*2;

    // Body mount flange dimensions
    flange_w = 50;
    flange_h = 40;
    flange_t = 5;

    difference() {
        union() {
            // Servo housing
            translate([0, 0, 0])
                cube([bracket_l, bracket_w, bracket_h], center=true);

            // Body mount flange
            translate([-bracket_l/2 - flange_t/2 + 1, 0, 0])
                cube([flange_t, flange_w, flange_h], center=true);

            // Output side reinforcement
            translate([bracket_l/2, 0, bracket_h/2])
                cylinder(d=bracket_w, h=wall_thickness);
        }

        // Servo pocket
        lx16a_pocket();

        // Shaft hole (top)
        translate([lx16a_length/2 - lx16a_shaft_offset, 0, bracket_h/2 - 2])
            cylinder(d=lx16a_horn_dia + 2, h=wall_thickness + 5);

        // Body mount holes
        translate([-bracket_l/2 - flange_t/2, 0, 0]) {
            for (dy = [-15, 15]) {
                for (dz = [-12, 12]) {
                    translate([0, dy, dz])
                        rotate([0, 90, 0])
                            cylinder(d=3.5, h=flange_t + 2, center=true);
                }
            }
        }

        // Wire channel
        translate([0, -bracket_w/2, -bracket_h/4])
            cube([12, wall_thickness*3, 10], center=true);
    }
}

// ============================================
// Femur Link - Upper leg (80mm)
// FIXED: Servo rotated 90° so shaft points horizontally (Y axis)
// ============================================
module femur_link() {
    // Servo box rotated: length along X, height along Y (for horizontal shaft)
    servo_box_l = lx16a_length + wall_thickness*2;  // Along leg (X)
    servo_box_w = lx16a_height + wall_thickness*2;  // Vertical (Z) - swapped
    servo_box_h = lx16a_width + wall_thickness*2;   // Toward body (Y) - swapped

    // Hub for coxa horn attachment
    hub_dia = 35;
    hub_height = 15;

    difference() {
        union() {
            // Coxa attachment hub
            translate([0, 0, 0])
                cylinder(d=hub_dia, h=hub_height, center=true);

            // Main tube section
            translate([femur_length/2 - 10, 0, 0])
                rotate([0, 90, 0])
                    cylinder(d=leg_tube_od, h=femur_length - 20);

            // Transition from hub to tube
            hull() {
                cylinder(d=hub_dia, h=hub_height, center=true);
                translate([20, 0, 0])
                    rotate([0, 90, 0])
                        cylinder(d=leg_tube_od, h=1);
            }

            // Servo mount at end (for tibia) - rotated orientation
            translate([femur_length - servo_box_l/2, 0, 0])
                cube([servo_box_l, servo_box_h, servo_box_w], center=true);
        }

        // Horn attachment hole (coxa side)
        cylinder(d=lx16a_shaft_dia + 1, h=hub_height + 2, center=true);

        // Horn screw holes (M2 = 2.2mm)
        for (a = [0:90:360]) {
            rotate([0, 0, a])
                translate([8, 0, 0])
                    cylinder(d=2.2, h=hub_height + 2, center=true);
        }

        // Wire channel through tube
        translate([femur_length/2, 0, 0])
            rotate([0, 90, 0])
                cylinder(d=leg_tube_id, h=femur_length + 10, center=true);

        // Servo pocket at end - ROTATED 90° around X axis
        translate([femur_length - servo_box_l/2, 0, 0])
            rotate([90, 0, 0])
                lx16a_pocket();

        // Shaft hole for tibia - now on SIDE (Y axis) not top
        translate([femur_length - lx16a_shaft_offset, servo_box_h/2, 0])
            rotate([90, 0, 0])
                cylinder(d=lx16a_horn_dia + 2, h=wall_thickness + 5);
    }
}

// ============================================
// Tibia Link - Lower leg (120mm)
// Hub attaches to femur servo (horizontal shaft)
// ============================================
module tibia_link() {
    hub_dia = 35;
    hub_height = 15;
    foot_dia = 20;

    difference() {
        union() {
            // Femur attachment hub - rotated to match horizontal servo shaft
            translate([0, 0, 0])
                rotate([90, 0, 0])
                    cylinder(d=hub_dia, h=hub_height, center=true);

            // Main leg tube - tapered
            hull() {
                translate([15, 0, 0])
                    rotate([0, 90, 0])
                        cylinder(d=leg_tube_od, h=1);
                translate([tibia_length - 15, 0, 0])
                    rotate([0, 90, 0])
                        cylinder(d=foot_dia, h=1);
            }

            // Transition from hub to tube
            hull() {
                rotate([90, 0, 0])
                    cylinder(d=hub_dia, h=hub_height, center=true);
                translate([15, 0, 0])
                    rotate([0, 90, 0])
                        cylinder(d=leg_tube_od, h=1);
            }

            // Foot mount
            translate([tibia_length, 0, 0])
                rotate([0, 90, 0])
                    cylinder(d=foot_dia, h=10);
        }

        // Horn attachment hole - horizontal (Y axis)
        rotate([90, 0, 0])
            cylinder(d=lx16a_shaft_dia + 1, h=hub_height + 2, center=true);

        // Horn screw holes (M2 = 2.2mm, 4 holes at 8mm radius)
        rotate([90, 0, 0])
            for (a = [0:90:360]) {
                rotate([0, 0, a])
                    translate([8, 0, 0])
                        cylinder(d=2.2, h=hub_height + 2, center=true);
            }

        // Wire channel
        translate([tibia_length/2, 0, 0])
            rotate([0, 90, 0])
                cylinder(d=8, h=tibia_length - 20, center=true);
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

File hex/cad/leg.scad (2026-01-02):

// Hexapod Leg - Parametric OpenSCAD Design
// Designed for SG90 servos (all 18 joints)

/* [Servo Dimensions] */
// SG90 micro servo
sg90_width = 12;
sg90_length = 23;
sg90_height = 29;
sg90_shaft_height = 4;
sg90_ear_width = 32;
sg90_ear_thickness = 2.5;
sg90_ear_offset = 15.5;  // from bottom

// HS-82MG servo (slightly larger)
hs82_width = 12;
hs82_length = 30;
hs82_height = 30;
hs82_shaft_height = 4;
hs82_ear_width = 40;
hs82_ear_thickness = 2.5;
hs82_ear_offset = 17;

/* [Leg Dimensions] */
coxa_length = 25;
femur_length = 55;
tibia_length = 75;
wall_thickness = 3;
clearance = 0.4;  // printer tolerance (increased for MG90S compatibility)

/* [Rendering] */
$fn = 32;

// Servo pocket module (for embedding servo)
module servo_pocket(type="sg90") {
    w = (type == "sg90") ? sg90_width : hs82_width;
    l = (type == "sg90") ? sg90_length : hs82_length;
    h = (type == "sg90") ? sg90_height : hs82_height;
    ear_w = (type == "sg90") ? sg90_ear_width : hs82_ear_width;
    ear_t = (type == "sg90") ? sg90_ear_thickness : hs82_ear_thickness;
    ear_off = (type == "sg90") ? sg90_ear_offset : hs82_ear_offset;

    c = clearance;

    union() {
        // Main body
        cube([l + c*2, w + c*2, h + c], center=true);
        // Mounting ears
        translate([0, 0, h/2 - ear_off])
            cube([ear_w + c*2, w + c*2, ear_t + c], center=true);
    }
}

// Horn/shaft hole
module shaft_hole(d=7, h=10) {
    cylinder(d=d + clearance*2, h=h, center=true);
}

// Coxa bracket - mounts SG90 for hip rotation
module coxa_bracket() {
    bracket_h = sg90_height + wall_thickness * 2;
    bracket_w = sg90_width + wall_thickness * 2;
    bracket_l = sg90_length + wall_thickness * 2;

    difference() {
        // Outer shell
        cube([bracket_l, bracket_w, bracket_h], center=true);

        // Servo pocket
        translate([0, 0, wall_thickness])
            servo_pocket("sg90");

        // Shaft hole (top)
        translate([0, 0, bracket_h/2 - 2])
            shaft_hole();

        // Wire channel
        translate([bracket_l/2, 0, 0])
            cube([wall_thickness*2, 6, 8], center=true);
    }
}

// Femur link - connects coxa to tibia
module femur_link() {
    link_w = sg90_width + wall_thickness * 2;
    link_h = sg90_height/2 + wall_thickness;

    difference() {
        union() {
            // Main beam
            cube([femur_length, link_w, link_h], center=true);

            // Servo mount end
            translate([femur_length/2 - sg90_length/2, 0, 0])
                cube([sg90_length + wall_thickness*2, link_w, sg90_height + wall_thickness], center=true);
        }

        // Servo pocket at end
        translate([femur_length/2 - sg90_length/2, 0, 0])
            servo_pocket("sg90");

        // Horn attachment hole (other end)
        translate([-femur_length/2 + 8, 0, 0])
            shaft_hole();
    }
}

// Tibia link - lower leg segment
module tibia_link() {
    link_w = 15;
    link_h = 8;

    difference() {
        union() {
            // Main beam
            hull() {
                translate([-tibia_length/2 + 8, 0, 0])
                    cylinder(d=link_w, h=link_h, center=true);
                translate([tibia_length/2 - 5, 0, 0])
                    cylinder(d=10, h=link_h, center=true);
            }
        }

        // Horn attachment hole
        translate([-tibia_length/2 + 8, 0, 0])
            shaft_hole();
    }
}

// Foot tip (print in TPU for grip)
module foot_tip() {
    cylinder(d1=12, d2=6, h=15, center=true);
}

// Body mount plate (1/6 segment)
module body_segment() {
    seg_angle = 60;
    inner_r = 30;
    outer_r = 100;
    thickness = 4;

    difference() {
        // Wedge shape
        linear_extrude(height=thickness)
            polygon([
                [0, 0],
                [outer_r * cos(seg_angle/2), outer_r * sin(seg_angle/2)],
                [outer_r * cos(-seg_angle/2), outer_r * sin(-seg_angle/2)]
            ]);

        // Inner cutout
        translate([0, 0, -1])
            cylinder(r=inner_r, h=thickness+2);

        // Coxa mount holes
        translate([70, 0, -1]) {
            cylinder(d=3.2, h=thickness+2);
            translate([15, 0, 0])
                cylinder(d=3.2, h=thickness+2);
        }
    }
}

// Preview all parts
module preview() {
    color("DarkGray") coxa_bracket();
    color("Gray") translate([50, 0, 0]) femur_link();
    color("LightGray") translate([120, 0, 0]) tibia_link();
    color("Black") translate([180, 0, 0]) foot_tip();
    color("Blue", 0.5) translate([0, 60, 0]) body_segment();
}

// Uncomment to render individual parts for printing:
// coxa_bracket();
// femur_link();
// tibia_link();
// foot_tip();
// body_segment();

preview();

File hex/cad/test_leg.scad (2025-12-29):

// Test Leg Print - One complete leg for fit testing
// Print this first before committing to all 6 legs
//
// PRINT SETTINGS:
//   Material: PLA or PETG
//   Layer height: 0.2mm
//   Infill: 20-30%
//   Supports: YES (for coxa bracket and femur)
//   Bed: 150x150mm minimum
//
// AFTER PRINTING:
//   1. Test fit servos (should slide in snugly)
//   2. Check horn shaft holes (7mm diameter)
//   3. Verify wall thickness is adequate
//   4. Adjust 'clearance' variable if too tight/loose

include <leg.scad>

// Arrange parts for printing on bed
module test_leg_plate() {
    // Coxa bracket - needs supports, print upright
    translate([0, 0, 0])
        coxa_bracket();

    // Femur link - print on side for strength
    translate([50, 0, sg90_height/2 + wall_thickness/2])
        rotate([90, 0, 0])
            femur_link();

    // Tibia link - simple, flat print
    translate([0, 50, 4])
        tibia_link();

    // Foot tip - optional, can print in TPU later
    translate([60, 50, 7.5])
        foot_tip();
}

// Alternative: Parts laid flat (less supports needed)
module test_leg_flat() {
    // Coxa bracket on its side
    translate([0, 0, (hs82_width + wall_thickness*2)/2])
        rotate([90, 0, 0])
            coxa_bracket();

    // Femur link flat
    translate([60, 0, (sg90_height + wall_thickness)/2])
        femur_link();

    // Tibia link
    translate([0, 40, 4])
        tibia_link();

    // Foot
    translate([60, 40, 7.5])
        foot_tip();
}

// CHOOSE ONE:
// test_leg_plate();   // Standard orientation with supports
test_leg_flat();       // Flat orientation, minimal supports

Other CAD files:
hex/cad/export_parts.scad

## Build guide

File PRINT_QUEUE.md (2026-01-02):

# Print Queue

Track print jobs for hexapod robot.

## JLC3DP Order

Ordering from [JLC3DP](https://jlc3dp.com/) - online 3D printing service.

**Quote page:** https://jlc3dp.com/3d-printing-quote

**STL files:** `hex/cad/stl/`

### Order Details

| Part | File | Qty | Material | Notes |
|---|---|-----|---|---|
| Coxa bracket | coxa_bracket.stl | 7 | PLA | +1 spare |
| Femur link | femur_link.stl | 7 | PLA | +1 spare |
| Tibia link | tibia_link.stl | 7 | PLA | +1 spare |
| Foot tip | foot_tip.stl | 7 | TPU | +1 spare |
| Body segment | body_segment.stl | 6 | PLA | |
| **Total** | | **34** | | |

### Print Settings (specify when ordering)

**PLA parts:**
- Technology: FDM
- Infill: 15-20%
- Layer: 0.2mm
- Color: Gray (or any)

**TPU parts (foot_tip):**
- Technology: FDM
- Material: TPU
- Infill: 20%
- Color: Black

### Cost Estimate

| Item | Cost |
|---|---|
| PLA parts (27×) | ~$35 |
| TPU parts (7×) | ~$10 |
| Shipping | ~$10-15 |
| **Total** | **~$55-60** |

### Timeline

| Stage | Time |
|---|---|
| Build | 2-5 days |
| Shipping | 7-14 days |
| **Total** | **~2-3 weeks** |

### Order Status

- [ ] Upload STL files
- [ ] Select materials and quantities
- [ ] Place order
- [ ] Order shipped
- [ ] Order received
- [ ] Verify fit with servo

---

## Part Quantities (Full Robot)

| Part | Per Leg | Legs | Body | Total | +Spare | Order |
|---|---|---|---|---|---|---|
| coxa_bracket | 1 | 6 | - | 6 | +1 | 7 |
| femur_link | 1 | 6 | - | 6 | +1 | 7 |
| tibia_link | 1 | 6 | - | 6 | +1 | 7 |
| foot_tip | 1 | 6 | - | 6 | +1 | 7 |
| body_segment | - | - | 6 | 6 | - | 6 |

## Print Settings Reference

### PLA Light (leg parts - optimized for weight)
```
Layer: 0.2mm
Infill: 15%
Walls: 2
Speed: 60mm/s
Temp: 210/60
```

### TPU Flexible (feet)
```
Layer: 0.2mm
Infill: 20%
Walls: 3
Speed: 25mm/s
Temp: 230/50
```

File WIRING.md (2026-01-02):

# Hexapod Wiring Diagram

## Architecture Overview

```
┌─────────────────────────────────────────────────────────────────────────────┐
│                         ESP32 CONTROLLER ARCHITECTURE                       │
├─────────────────────────────────────────────────────────────────────────────┤
│                                                                             │
│   ┌─────────────────────┐    UART    ┌─────────────────────┐               │
│   │    Pi Zero 2W       │◄──────────►│       ESP32         │               │
│   │   (High-Level)      │            │   (Real-Time)       │               │
│   │    [OPTIONAL]       │            │                     │               │
│   │                     │            │                     │               │
│   │  • OpenCV / Camera  │  Commands  │  • Servo Control    │               │
│   │  • Path Planning    │  ───────►  │  • Gait Engine      │               │
│   │  • Web UI           │            │  • IMU Processing   │               │
│   │                     │  Status    │  • I2C Bus Master   │               │
│   │                     │  ◄───────  │  • WiFi / BT        │               │
│   └─────────────────────┘            └─────────────────────┘               │
│            │                                   │                            │
│        [Camera]                          [I2C Bus]                          │
│                                               │                             │
│                          ┌────────────────────┼────────────────────┐        │
│                          │                    │                    │        │
│                    ┌─────┴─────┐        ┌─────┴─────┐        ┌─────┴─────┐  │
│                    │  MPU6050  │        │ PCA9685x2 │        │  Sensors  │  │
│                    │   (IMU)   │        │  (Servos) │        │ VL53/INA  │  │
│                    └───────────┘        └───────────┘        └───────────┘  │
│                                                                             │
└─────────────────────────────────────────────────────────────────────────────┘

Note: Pi Zero 2W is optional. ESP32 can run standalone with WiFi/Bluetooth control.
```

## Physical Layout (Top View)

```
                          FRONT
                            │
              L1 ─────────────────────── R1
             ╱ ╲           │           ╱ ╲
           Coxa            │         Coxa
            │              │           │
          Femur            │         Femur
            │              │           │
          Tibia            │         Tibia
            │              │           │
          [foot]           │        [foot]
                           │
    L2 ──────────────── [BODY] ──────────────── R2
   ╱ ╲                     │                   ╱ ╲
 Coxa                      │                 Coxa
  │                        │                   │
Femur                      │                 Femur
  │                        │                   │
Tibia                      │                 Tibia
  │                        │                   │
[foot]                     │                [foot]
                           │
              L3 ─────────────────────── R3
             ╱ ╲           │           ╱ ╲
           Coxa            │         Coxa
            │              │           │
          Femur            │         Femur
            │              │           │
          Tibia            │         Tibia
            │              │           │
          [foot]           │        [foot]
                           │
                         REAR
```

## Leg Assembly Detail

```
                BODY PLATE
                    │
    ┌───────────────┴───────────────┐
    │                               │
    │  ┌─────────────────────────┐  │
    │  │      SG90 / HS-82MG     │  │  ← Coxa servo (horizontal rotation)
    │  │      [COXA SERVO]       │  │
    │  └──────────┬──────────────┘  │
    │             │ 25mm             │
    └─────────────┼─────────────────┘
                  │
         ┌────────┴────────┐
         │    HS-82MG      │  ← Femur servo (vertical lift) - use metal gear
         │  [FEMUR SERVO]  │
         └────────┬────────┘
                  │
                  │ 55mm
                  │
         ┌────────┴────────┐
         │      SG90       │  ← Tibia servo (vertical extend)
         │  [TIBIA SERVO]  │
         └────────┬────────┘
                  │
                  │ 75mm
                  │
                  ▼
              [FOOT TIP]
               (TPU)
```

## Power Distribution

```
    ┌─────────────────────────────────────────────────────────────────┐
    │                        3S Li-Ion Battery                        │
    │                     11.1V  3.5Ah  (Titan)                       │
    └───────────────────────────┬─────────────────────────────────────┘
                                │
                          (+)   │   (-)
                           │    │    │
                           ▼    │    ▼
                    ┌──────────────────────┐
                    │  Turnigy PLUSH 60A   │
                    │     ESC (as BEC)     │
                    │    IN: 11.1V         │
                    │    OUT: 5V 3A        │
                    └──────────┬───────────┘
                               │
              ┌────────────────┼────────────────┬────────────────┐
              │                │                │                │
              ▼                ▼                ▼                ▼
    ┌─────────────────┐ ┌─────────────┐ ┌─────────────┐ ┌─────────────────┐
    │   PCA9685 #1    │ │    ESP32    │ │ Pi Zero 2W  │ │   PCA9685 #2    │
    │   V+ = 5V       │ │   VIN=5V    │ │   5V pin    │ │   V+ = 5V       │
    │   (addr 0x40)   │ │             │ │ [OPTIONAL]  │ │   (addr 0x41)   │
    └─────────────────┘ └─────────────┘ └─────────────┘ └─────────────────┘
```

## UART Connection (ESP32 ↔ Zero) [OPTIONAL]

```
    ┌─────────────────────────────┐      ┌─────────────────────────────┐
    │        Pi Zero 2W           │      │           ESP32             │
    │                             │      │                             │
    │   GPIO 14 (TXD) ────────────┼──────┼──► GPIO 16 (UART2 RX)       │
    │                             │      │                             │
    │   GPIO 15 (RXD) ◄───────────┼──────┼─── GPIO 17 (UART2 TX)       │
    │                             │      │                             │
    │   GND ──────────────────────┼──────┼─── GND                      │
    │                             │      │                             │
    └─────────────────────────────┘      └─────────────────────────────┘

    Protocol: 115200 baud, 8N1

    Commands (Zero → ESP32):
      "W:100,0\n"     Walk forward 100mm
      "T:45\n"        Turn 45 degrees
      "S\n"           Stop
      "G:tripod\n"    Set gait to tripod
      "H:50\n"        Set height to 50mm

    Status (ESP32 → Zero):
      "OK\n"
      "IMU:roll,pitch,yaw\n"
      "ERR:message\n"

    Note: UART is only needed if using Pi Zero for camera/vision.
    ESP32 can operate standalone via WiFi or Bluetooth.
```

## I2C Bus (ESP32 as Master)

```
    ┌─────────────────────────────────────────────────────────────────────┐
    │                             ESP32                                   │
    │                                                                     │
    │   3.3V ─────┬────────────────────────────────────────────────────   │
    │             │                                                       │
    │   GND  ─────┼───┬────────────────────────────────────────────────   │
    │             │   │                                                   │
    │   GPIO21 ───┼───┼───┬────────────────────────────────────────────   │ (I2C SDA)
    │             │   │   │                                               │
    │   GPIO22 ───┼───┼───┼───┬────────────────────────────────────────   │ (I2C SCL)
    │             │   │   │   │                                           │
    └─────────────┼───┼───┼───┼───────────────────────────────────────────┘
                  │   │   │   │
    ┌─────────────┴───┴───┴───┴─────────┐
    │           I2C Bus                  │
    │    (directly connect all below)    │
    └──┬──────────┬──────────┬──────────┬──────────┬──────────┬───────────┘
       │          │          │          │          │          │
       ▼          ▼          ▼          ▼          ▼          ▼
   ┌───────┐  ┌───────┐  ┌───────┐  ┌───────┐  ┌───────┐  ┌───────┐
   │MPU6050│  │PCA9685│  │PCA9685│  │VL53L0X│  │VL53L0X│  │VL53L0X│
   │ 0x68  │  │ 0x40  │  │ 0x41  │  │ 0x29* │  │ 0x30* │  │ 0x31* │
   │ (IMU) │  │ (#1)  │  │ (#2)  │  │(front)│  │(left) │  │(right)│
   └───────┘  └───────┘  └───────┘  └───────┘  └───────┘  └───────┘

   * VL53L0X default address is 0x29. Use XSHUT pins to set unique addresses.
```

## VL53L0X Address Configuration

```
    ESP32
    ┌─────────────────────┐
    │ GPIO25 ─────────────┼──► VL53L0X #1 XSHUT (front)  → addr 0x29
    │ GPIO26 ─────────────┼──► VL53L0X #2 XSHUT (left)   → addr 0x30
    │ GPIO27 ─────────────┼──► VL53L0X #3 XSHUT (right)  → addr 0x31
    └─────────────────────┘

    Boot sequence:
    1. Hold all XSHUT low (sensors off)
    2. Release XSHUT #1, set address to 0x29
    3. Release XSHUT #2, set address to 0x30
    4. Release XSHUT #3, set address to 0x31
```

## INA219 Battery Monitor

```
    ┌─────────────────────────────────────────────────────────────────┐
    │                       INA219 (addr 0x40*)                       │
    │                                                                 │
    │   VIN- ◄─── Battery (-)                                         │
    │   VIN+ ◄─── Battery (+) ───► To ESC/BEC                         │
    │                                                                 │
    │   VCC  ◄─── 3.3V (from Pico)                                    │
    │   GND  ◄─── GND                                                 │
    │   SDA  ◄─── I2C SDA                                             │
    │   SCL  ◄─── I2C SCL                                             │
    │                                                                 │
    └─────────────────────────────────────────────────────────────────┘

    * Default 0x40 conflicts with PCA9685 #1. Solder A0 jumper → 0x41
      But that conflicts with PCA9685 #2. Use A0+A1 → 0x44 or 0x45
```

## Camera Connection (Zero Only)

```
    ┌─────────────────────────────────────────────────────────────────┐
    │                        Pi Zero 2W                               │
    │                                                                 │
    │   ┌─────────────────┐                                           │
    │   │  CSI Connector  │◄─── Pi Zero Camera Cable (narrow end)     │
    │   │   (22-pin)      │                                           │
    │   └─────────────────┘                                           │
    │                                                                 │
    └─────────────────────────────────────────────────────────────────┘
                                      │
                                      │ (15cm cable)
                                      │
    ┌─────────────────────────────────┴───────────────────────────────┐
    │                     Pi Camera v1.3                              │
    │                   ┌─────────────────┐                           │
    │                   │  CSI Connector  │◄─── Standard end of cable │
    │                   │   (15-pin)      │                           │
    │                   └─────────────────┘                           │
    │                        OV5647                                   │
    │                         5MP                                     │
    └─────────────────────────────────────────────────────────────────┘

    Note: Pi Zero uses narrower 22-pin connector, need special cable!
```

## Servo Channel Mapping

```
    ┌─────────────────────────────────────────────────────────────────┐
    │                        PCA9685 #1 (0x40)                        │
    ├─────────┬─────────┬─────────┬─────────┬─────────┬─────────┬─────┤
    │  CH 0   │  CH 1   │  CH 2   │  CH 3   │  CH 4   │  CH 5   │ ... │
    │ L1 Coxa │L1 Femur │L1 Tibia │ L2 Coxa │L2 Femur │L2 Tibia │     │
    │  SG90   │ HS-82MG │  SG90   │  SG90   │ HS-82MG │  SG90   │     │
    └────┬────┴────┬────┴────┬────┴────┬────┴────┬────┴────┬────┴─────┘
         │         │         │         │         │         │
         ▼         ▼         ▼         ▼         ▼         ▼
       ┌───┐     ┌───┐     ┌───┐     ┌───┐     ┌───┐     ┌───┐
       │L1 │     │L1 │     │L1 │     │L2 │     │L2 │     │L2 │
       │hip│     │thigh    │calf│     │hip│     │thigh    │calf│
       └───┘     └───┘     └───┘     └───┘     └───┘     └───┘

    ┌─────────────────────────────────────────────────────────────────┐
    │                   PCA9685 #1 (0x40) continued                   │
    ├─────────┬─────────┬─────────┬─────────┬─────────┬─────────┬─────┤
    │  CH 6   │  CH 7   │  CH 8   │  CH 9   │  CH 10  │  CH 11  │ ... │
    │ L3 Coxa │L3 Femur │L3 Tibia │ R1 Coxa │R1 Femur │R1 Tibia │     │
    │  SG90   │ HS-82MG │  SG90   │  SG90   │ HS-82MG │  SG90   │     │
    └────┬────┴────┬────┴────┬────┴────┬────┴────┬────┴────┬────┴─────┘
         │         │         │         │         │         │
         ▼         ▼         ▼         ▼         ▼         ▼
       ┌───┐     ┌───┐     ┌───┐     ┌───┐     ┌───┐     ┌───┐
       │L3 │     │L3 │     │L3 │     │R1 │     │R1 │     │R1 │
       │hip│     │thigh    │calf│     │hip│     │thigh    │calf│
       └───┘     └───┘     └───┘     └───┘     └───┘     └───┘

    ┌─────────────────────────────────────────────────────────────────┐
    │                        PCA9685 #2 (0x41)                        │
    ├─────────┬─────────┬─────────┬─────────┬─────────┬─────────┬─────┤
    │  CH 0   │  CH 1   │  CH 2   │  CH 3   │  CH 4   │  CH 5   │     │
    │ R2 Coxa │R2 Femur │R2 Tibia │ R3 Coxa │R3 Femur │R3 Tibia │     │
    │  SG90   │ HS-82MG │  SG90   │  SG90   │ HS-82MG │  SG90   │     │
    └────┬────┴────┬────┴────┬────┴────┬────┴────┬────┴────┬────┴─────┘
         │         │         │         │         │         │
         ▼         ▼         ▼         ▼         ▼         ▼
       ┌───┐     ┌───┐     ┌───┐     ┌───┐     ┌───┐     ┌───┐
       │R2 │     │R2 │     │R2 │     │R3 │     │R3 │     │R3 │
       │hip│     │thigh    │calf│     │hip│     │thigh    │calf│
       └───┘     └───┘     └───┘     └───┘     └───┘     └───┘

    Servo mix: 12x SG90 (coxa, tibia) + 6x HS-82MG (femur - high torque)
```

## Complete System Overview

```
┌─────────────────────────────────────────────────────────────────────────────┐
│                              HEXAPOD SYSTEM                                 │
├─────────────────────────────────────────────────────────────────────────────┤
│                                                                             │
│   ┌─────────────┐                                                           │
│   │   BATTERY   │                                                           │
│   │  3S 11.1V   │                                                           │
│   │  (Titan)    │                                                           │
│   └──────┬──────┘                                                           │
│          │                                                                  │
│          ├────────────────────────────────────────────┐                     │
│          │                                            │                     │
│          ▼                                            ▼                     │
│   ┌─────────────┐                              ┌─────────────┐              │
│   │  INA219     │                              │ PLUSH 60A   │              │
│   │  (monitor)  │                              │  ESC/BEC    │              │
│   └─────────────┘                              └──────┬──────┘              │
│                                                       │ 5V 3A               │
│              ┌────────────────────────────────────────┼──────────┐          │
│              │                    │                   │          │          │
│              ▼                    ▼                   ▼          ▼          │
│       ┌─────────────┐      ┌─────────────┐     ┌──────────┐ ┌──────────┐    │
│       │ Pi Zero 2W  │ UART │    ESP32    │     │ PCA9685  │ │ PCA9685  │    │
│       │ [OPTIONAL]  │◄────►│             │     │   #1     │ │   #2     │    │
│       │  • Camera   │      │  • Servos   │     │  0x40    │ │  0x41    │    │
│       │  • Vision   │      │  • IMU      │     └────┬─────┘ └────┬─────┘    │
│       │  • Planning │      │  • Sensors  │          │            │          │
│       └──────┬──────┘      │  • WiFi/BT  │          │            │          │
│              │             └──────┬──────┘          │            │          │
│         [Camera]            [I2C Bus]               │            │          │
│         Pi v1.3                   │                 │            │          │
│                    ┌──────────────┼─────────┐       │            │          │
│                    │              │         │       │            │          │
│                    ▼              ▼         ▼       │            │          │
│               ┌────────┐    ┌────────┐ ┌────────┐   │            │          │
│               │MPU6050 │    │VL53L0X │ │INA219  │   │            │          │
│               │  IMU   │    │  x3    │ │(power) │   │            │          │
│               └────────┘    └────────┘ └────────┘   │            │          │
│                                                     │            │          │
│    ┌────────────────────────────────────────────────┴────────────┘          │
│    │         │         │         │         │         │                      │
│    ▼         ▼         ▼         ▼         ▼         ▼                      │
│  ┌───┐     ┌───┐     ┌───┐     ┌───┐     ┌───┐     ┌───┐                    │
│  │L1 │     │L2 │     │L3 │     │R1 │     │R2 │     │R3 │                    │
│  │3x │     │3x │     │3x │     │3x │     │3x │     │3x │                    │
│  └───┘     └───┘     └───┘     └───┘     └───┘     └───┘                    │
│                                                                             │
│  Servos: 18x SG90 (or mix with HS-82MG for femur joints)                    │
│                                                                             │
└─────────────────────────────────────────────────────────────────────────────┘
```

## Pin Summary

### ESP32 (WROOM-32)
| GPIO | Function | Connected To |
|---|---|---|
| GPIO16 | UART2 RX | Zero GPIO 14 (TXD) [optional] |
| GPIO17 | UART2 TX | Zero GPIO 15 (RXD) [optional] |
| GPIO21 | I2C SDA | All I2C devices |
| GPIO22 | I2C SCL | All I2C devices |
| GPIO25 | Digital Out | VL53L0X #1 XSHUT |
| GPIO26 | Digital Out | VL53L0X #2 XSHUT |
| GPIO27 | Digital Out | VL53L0X #3 XSHUT |
| VIN | 5V Power | From BEC |
| GND | Ground | Common |

### Pi Zero 2W [OPTIONAL - for camera/vision]
| GPIO | Function | Connected To |
|---|---|---|
| GPIO 14 | UART TXD | ESP32 GPIO16 (RX) |
| GPIO 15 | UART RXD | ESP32 GPIO17 (TX) |
| CSI | Camera | Pi Camera v1.3 |
| 5V | Power | From BEC |
| GND | Ground | Common |

### I2C Addresses
| Address | Device |
|---|---|
| 0x29 | VL53L0X #1 (front) |
| 0x30 | VL53L0X #2 (left) |
| 0x31 | VL53L0X #3 (right) |
| 0x40 | PCA9685 #1 |
| 0x41 | PCA9685 #2 |
| 0x44 | INA219 (A0+A1 soldered) |
| 0x68 | MPU6050 |

## Servo Wire Colors

```
    ┌─────────────────────────────────┐
    │         SERVO CONNECTOR         │
    │                                 │
    │   ┌─────┬─────┬─────┐           │
    │   │ BRN │ RED │ ORG │           │
    │   │ GND │ V+  │ SIG │           │
    │   │     │ 5V  │ PWM │           │
    │   └──┬──┴──┬──┴──┬──┘           │
    │      │     │     │              │
    │      │     │     └───► PCA9685 PWM channel
    │      │     └─────────► PCA9685 V+ (from BEC)
    │      └───────────────► PCA9685 GND
    │                                 │
    └─────────────────────────────────┘
```

## Notes

- ESP32 handles all control (servos, IMU, sensors, WiFi, Bluetooth)
- Pi Zero is optional - only needed for camera/vision features
- UART at 115200 baud for inter-controller communication (if using Zero)
- All servos receive 5V power from ESC BEC through PCA9685 V+ terminals
- I2C uses 3.3V logic (ESP32 GPIO voltage)
- PCA9685 #2 needs A0 address jumper soldered to use 0x41
- INA219 needs A0+A1 jumpers soldered to avoid address conflict (0x44)
- VL53L0X sensors need XSHUT pin sequence to set unique addresses
- Pi Zero camera uses narrower connector - need special cable
- Keep servo wires bundled and routed through body to legs
- Use servo wire extensions (15-20cm) for clean routing
- ESP32 can be controlled via WiFi web UI or Bluetooth gamepad

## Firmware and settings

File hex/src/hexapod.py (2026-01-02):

"""
Hexapod Robot Controller
For ESP32 (MicroPython) or Pi Zero (CPython)

Hardware:
- 2x PCA9685 PWM drivers (I2C 0x40, 0x41)
- 12x SG90 servos (coxa, tibia joints)
- 6x MG90S servos (femur joints - metal gear for torque)
- 3S Li-Ion battery (11.1V) with dual 5V 5A UBEC
"""

import json
import os
from math import atan2, acos, sqrt, degrees, radians, cos, sin

# Leg geometry (mm) - adjust to match your 3D printed parts
COXA_LENGTH = 25
FEMUR_LENGTH = 55
TIBIA_LENGTH = 75

# Servo PWM defaults (overridden by calibration file)
SERVO_MIN = 500   # 0 degrees
SERVO_MAX = 2500  # 180 degrees
SERVO_CENTER = 1500  # 90 degrees

# Leg numbering (top view, front is 0 degrees)
#      FRONT (0)
#   L1       R1    (330, 30)
#   L2--[B]--R2    (270, 90)
#   L3       R3    (210, 150)
#      REAR (180)

LEG_ANGLES = {
    'L1': 330, 'R1': 30,
    'L2': 270, 'R2': 90,
    'L3': 210, 'R3': 150,
}

# Default servo channel mapping (pca_index, channel)
# Channels 0-15 on PCA9685 #1 (0x40), 16-31 on #2 (0x41)
DEFAULT_SERVO_MAP = {
    'L1': {'coxa': (0, 0), 'femur': (0, 1), 'tibia': (0, 2)},
    'L2': {'coxa': (0, 3), 'femur': (0, 4), 'tibia': (0, 5)},
    'L3': {'coxa': (0, 6), 'femur': (0, 7), 'tibia': (0, 8)},
    'R1': {'coxa': (0, 9), 'femur': (0, 10), 'tibia': (0, 11)},
    'R2': {'coxa': (1, 0), 'femur': (1, 1), 'tibia': (1, 2)},
    'R3': {'coxa': (1, 3), 'femur': (1, 4), 'tibia': (1, 5)},
}

# Default servo directions (1 or -1 to flip)
DEFAULT_SERVO_DIR = {
    'L1': {'coxa': 1, 'femur': 1, 'tibia': 1},
    'L2': {'coxa': 1, 'femur': 1, 'tibia': 1},
    'L3': {'coxa': 1, 'femur': 1, 'tibia': 1},
    'R1': {'coxa': -1, 'femur': -1, 'tibia': -1},
    'R2': {'coxa': -1, 'femur': -1, 'tibia': -1},
    'R3': {'coxa': -1, 'femur': -1, 'tibia': -1},
}


def clamp(val, min_val, max_val):
    """Clamp value to range."""
    return max(min_val, min(max_val, val))


def leg_ik(x, y, z, coxa_len=COXA_LENGTH, femur_len=FEMUR_LENGTH, tibia_len=TIBIA_LENGTH):
    """
    Inverse kinematics for single leg.

    Args:
        x: Forward/back from coxa pivot (mm)
        y: Left/right from coxa pivot (mm)
        z: Up/down from coxa pivot (mm, negative = down)
        coxa_len, femur_len, tibia_len: Link lengths (mm)

    Returns:
        (coxa_angle, femur_angle, tibia_angle) in degrees
        Angles are servo positions (0-180, 90 = center)
        Returns None if target is completely unreachable.
    """
    # Handle edge case: target at origin
    if x == 0 and y == 0:
        x = 0.1  # Small offset to avoid atan2(0,0)

    # Coxa angle (rotation in XY plane)
    coxa_angle = degrees(atan2(y, x))

    # Horizontal distance from coxa to foot
    xy_dist = sqrt(x**2 + y**2) - coxa_len

    # Handle case where target is inside coxa length
    if xy_dist < 0:
        xy_dist = 1  # Minimum reach

    # Direct distance from femur pivot to foot
    foot_dist = sqrt(xy_dist**2 + z**2)

    # Check reachability
    max_reach = femur_len + tibia_len
    min_reach = abs(femur_len - tibia_len)

    clamped = False
    if foot_dist > max_reach or foot_dist < min_reach:
        # Out of reach - clamp to nearest valid
        foot_dist = clamp(foot_dist, min_reach + 1, max_reach - 1)
        clamped = True

    # Tibia angle (law of cosines)
    cos_tibia = (femur_len**2 + tibia_len**2 - foot_dist**2) / \
                (2 * femur_len * tibia_len)
    tibia_angle = degrees(acos(clamp(cos_tibia, -1, 1)))

    # Femur angle
    cos_femur = (femur_len**2 + foot_dist**2 - tibia_len**2) / \
                (2 * femur_len * foot_dist)
    femur_angle = degrees(atan2(-z, xy_dist)) + degrees(acos(clamp(cos_femur, -1, 1)))

    # Convert to servo angles (centered at 90)
    coxa_servo = 90 + coxa_angle
    femur_servo = femur_angle
    tibia_servo = 180 - tibia_angle  # Tibia typically inverted

    # Clamp all angles to valid servo range (0-180)
    coxa_servo = clamp(coxa_servo, 0, 180)
    femur_servo = clamp(femur_servo, 0, 180)
    tibia_servo = clamp(tibia_servo, 0, 180)

    if clamped:
        print(f"Warning: IK target ({x:.1f}, {y:.1f}, {z:.1f}) out of reach, clamped")

    return coxa_servo, femur_servo, tibia_servo


class Hexapod:
    """Main hexapod controller class."""

    def __init__(self, pca_drivers=None, calibration_file='calibration.json', simulate=False):
        """
        Args:
            pca_drivers: List of 2 PCA9685 driver instances (or None for simulation)
            calibration_file: Path to calibration JSON file
            simulate: If True, don't access hardware
        """
        self.simulate = simulate or pca_drivers is None
        self.pca = pca_drivers or [None, None]

        # Load calibration or use defaults
        self.calibration = self._load_calibration(calibration_file)

        # Build servo map from calibration
        self._build_servo_map()

        # Track leg positions (x, y, z) for each leg
        self.leg_positions = {}
        for leg in self.servo_map.keys():
            self.leg_positions[leg] = (80, 0, -40)  # Default standing (40mm for MG90S)

    def _load_calibration(self, calibration_file):
        """Load calibration from JSON file."""
        if os.path.exists(calibration_file):
            try:
                with open(calibration_file, 'r') as f:
                    return json.load(f)
            except Exception as e:
                print(f"Warning: Could not load calibration: {e}")
        return None

    def _build_servo_map(self):
        """Build servo map from calibration or defaults."""
        self.servo_map = {}
        self.servo_dir = {}
        self.servo_range = {}

        legs = ['L1', 'L2', 'L3', 'R1', 'R2', 'R3']
        joints = ['coxa', 'femur', 'tibia']

        for leg in legs:
            self.servo_map[leg] = {}
            self.servo_dir[leg] = {}
            self.servo_range[leg] = {}

            for joint in joints:
                if self.calibration and leg in self.calibration:
                    cal = self.calibration[leg][joint]
                    channel = cal['channel']
                    pca_idx = 0 if channel < 16 else 1
                    ch = channel if channel < 16 else channel - 16

                    self.servo_map[leg][joint] = (pca_idx, ch)
                    self.servo_dir[leg][joint] = cal.get('direction', 1)
                    self.servo_range[leg][joint] = {
                        'min': cal.get('min', SERVO_MIN),
                        'max': cal.get('max', SERVO_MAX),
                        'center': cal.get('center', SERVO_CENTER),
                    }
                else:
                    # Use defaults
                    self.servo_map[leg][joint] = DEFAULT_SERVO_MAP[leg][joint]
                    self.servo_dir[leg][joint] = DEFAULT_SERVO_DIR[leg][joint]
                    self.servo_range[leg][joint] = {
                        'min': SERVO_MIN,
                        'max': SERVO_MAX,
                        'center': SERVO_CENTER,
                    }

    def angle_to_pulse(self, leg, joint, angle):
        """Convert angle (0-180) to calibrated PWM pulse width (us)."""
        angle = clamp(angle, 0, 180)
        sr = self.servo_range[leg][joint]

        # Map 0-180 to min-max pulse range
        pulse = sr['min'] + (angle / 180.0) * (sr['max'] - sr['min'])
        return int(pulse)

    def set_servo(self, leg, joint, angle):
        """Set single servo to angle (0-180 degrees)."""
        pca_idx, channel = self.servo_map[leg][joint]
        direction = self.servo_dir[leg][joint]

        # Apply direction (flip if needed)
        if direction < 0:
            angle = 180 - angle

        pulse = self.angle_to_pulse(leg, joint, angle)

        if self.simulate:
            # Just track the position
            pass
        else:
            self.pca[pca_idx].set_pwm(channel, pulse)

    def move_leg(self, leg, x, y, z):
        """Move single leg to position using IK."""
        coxa, femur, tibia = leg_ik(x, y, z)

        self.set_servo(leg, 'coxa', coxa)
        self.set_servo(leg, 'femur', femur)
        self.set_servo(leg, 'tibia', tibia)

        self.leg_positions[leg] = (x, y, z)

    def stand(self, height=50):
        """
        Move to standing position.

        Coordinate System:
        - Each leg's IK uses a local coordinate frame where:
          - X axis points outward from the body along the leg's mounting angle
          - Y axis is perpendicular to X in the horizontal plane
          - Z axis points up (negative Z = down toward ground)
        - The LEG_ANGLES define each leg's mounting angle in world frame
        - We calculate (x, y) in world frame then pass to move_leg()
        - The IK interprets these as leg-local coordinates
        """
        for leg in self.servo_map.keys():
            # Position legs outward based on their mounting angle
            # This creates a symmetric stance where each leg points outward
            angle_rad = radians(LEG_ANGLES[leg])
            x = 80 * cos(angle_rad)
            y = 80 * sin(angle_rad)
            self.move_leg(leg, x, y, -height)

    def center_all(self):
        """Move all servos to 90 degrees (calibration position)."""
        for leg in self.servo_map.keys():
            for joint in ['coxa', 'femur', 'tibia']:
                self.set_servo(leg, joint, 90)

    def shutdown(self):
        """Disable all servos (no holding torque)."""
        if self.simulate:
            return

        # Disable only the channels we're actually using
        for leg in self.servo_map:
            for joint in self.servo_map[leg]:
                pca_idx, channel = self.servo_map[leg][joint]
                if self.pca[pca_idx]:
                    self.pca[pca_idx].set_pwm(channel, 0)

    def get_leg_position(self, leg):
        """Get current (x, y, z) position of leg."""
        return self.leg_positions.get(leg, (80, 0, -40))


def create_hexapod(simulate=False):
    """
    Factory function to create a Hexapod with drivers initialized.

    Args:
        simulate: If True, run without hardware

    Returns:
        Hexapod instance
    """
    if simulate:
        return Hexapod(pca_drivers=None, simulate=True)

    try:
        from pca9685 import PCA9685
        pca1 = PCA9685(address=0x40, freq=50)
        pca2 = PCA9685(address=0x41, freq=50)
        return Hexapod(pca_drivers=[pca1, pca2])
    except Exception as e:
        print(f"Hardware init failed: {e}")
        print("Running in simulation mode")
        return Hexapod(pca_drivers=None, simulate=True)


if __name__ == '__main__':
    # Test IK calculations
    print("Hexapod IK Test")
    print("=" * 40)

    test_positions = [
        (80, 0, -50),   # Default stand
        (100, 0, -30),  # Leg extended forward
        (60, 30, -60),  # Leg to side and down
        (50, 0, -80),   # Leg tucked under
    ]

    for x, y, z in test_positions:
        angles = leg_ik(x, y, z)
        print(f"\nPosition ({x}, {y}, {z}):")
        print(f"  Coxa:  {angles[0]:.1f} deg")
        print(f"  Femur: {angles[1]:.1f} deg")
        print(f"  Tibia: {angles[2]:.1f} deg")

    # Test hexapod in simulation
    print("\n" + "=" * 40)
    print("Creating hexapod (simulation mode)...")
    hex = create_hexapod(simulate=True)
    hex.stand()
    print("Standing position set")
    print(f"L1 position: {hex.get_leg_position('L1')}")

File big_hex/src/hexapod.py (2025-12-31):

"""
Big Hex - Hexapod Robot Controller

Main controller for 18-servo hexapod using LX-16A serial bus servos.
Includes inverse kinematics and leg coordination.
"""

import json
import os
from math import atan2, acos, sqrt, degrees, radians, cos, sin
from typing import Dict, List, Optional, Tuple

from lx16a import LX16A, BROADCAST_ID


# =============================================================================
# Geometry (from CAD - leg.scad)
# =============================================================================

COXA_LENGTH = 50    # mm - hip segment
FEMUR_LENGTH = 80   # mm - upper leg
TIBIA_LENGTH = 120  # mm - lower leg
BODY_RADIUS = 175   # mm - center to leg mount

# Leg positions around body (degrees from front, counterclockwise)
# Front is 0°, looking down from above
#
#      FRONT (0°)
#   L1 (30°)    R1 (330°)
#   L2 (90°)    R2 (270°)
#   L3 (150°)   R3 (210°)
#      REAR (180°)

LEG_ANGLES = {
    'L1': 30,   'R1': 330,
    'L2': 90,   'R2': 270,
    'L3': 150,  'R3': 210,
}

# Default servo ID mapping
# Each leg has 3 servos: coxa (hip), femur (upper), tibia (lower)
DEFAULT_SERVO_IDS = {
    'L1': {'coxa': 1,  'femur': 2,  'tibia': 3},
    'L2': {'coxa': 4,  'femur': 5,  'tibia': 6},
    'L3': {'coxa': 7,  'femur': 8,  'tibia': 9},
    'R1': {'coxa': 10, 'femur': 11, 'tibia': 12},
    'R2': {'coxa': 13, 'femur': 14, 'tibia': 15},
    'R3': {'coxa': 16, 'femur': 17, 'tibia': 18},
}

# Servo direction (1 = normal, -1 = reversed)
# Right side legs are mirrored
DEFAULT_SERVO_DIR = {
    'L1': {'coxa': 1, 'femur': 1, 'tibia': 1},
    'L2': {'coxa': 1, 'femur': 1, 'tibia': 1},
    'L3': {'coxa': 1, 'femur': 1, 'tibia': 1},
    'R1': {'coxa': -1, 'femur': -1, 'tibia': -1},
    'R2': {'coxa': -1, 'femur': -1, 'tibia': -1},
    'R3': {'coxa': -1, 'femur': -1, 'tibia': -1},
}


# =============================================================================
# Utility Functions
# =============================================================================

def clamp(val: float, min_val: float, max_val: float) -> float:
    """Clamp value to range."""
    return max(min_val, min(max_val, val))


def leg_ik(x: float, y: float, z: float,
           coxa_len: float = COXA_LENGTH,
           femur_len: float = FEMUR_LENGTH,
           tibia_len: float = TIBIA_LENGTH) -> Optional[Tuple[float, float, float]]:
    """
    Inverse kinematics for single leg.

    Coordinate system (leg's local frame):
        x: Forward/back from coxa pivot (positive = forward)
        y: Left/right from coxa pivot (positive = outward from body)
        z: Up/down from coxa pivot (negative = down)

    Args:
        x, y, z: Target foot position in mm
        coxa_len, femur_len, tibia_len: Link lengths in mm

    Returns:
        (coxa_angle, femur_angle, tibia_angle) in degrees (0-240 range for LX-16A)
        Returns None if target is unreachable.
    """
    # Handle edge case: target at origin
    if x == 0 and y == 0:
        x = 0.1

    # Coxa angle (rotation in XY plane)
    coxa_angle = degrees(atan2(y, x))

    # Horizontal distance from coxa pivot to foot
    xy_dist = sqrt(x**2 + y**2) - coxa_len

    if xy_dist < 0:
        xy_dist = 1  # Minimum reach

    # Direct distance from femur pivot to foot
    foot_dist = sqrt(xy_dist**2 + z**2)

    # Check reachability
    max_reach = femur_len + tibia_len
    min_reach = abs(femur_len - tibia_len)

    if foot_dist > max_reach or foot_dist < min_reach:
        # Clamp to nearest valid distance
        foot_dist = clamp(foot_dist, min_reach + 1, max_reach - 1)

    # Tibia angle (law of cosines)
    cos_tibia = (femur_len**2 + tibia_len**2 - foot_dist**2) / (2 * femur_len * tibia_len)
    tibia_angle = degrees(acos(clamp(cos_tibia, -1, 1)))

    # Femur angle
    cos_femur = (femur_len**2 + foot_dist**2 - tibia_len**2) / (2 * femur_len * foot_dist)
    femur_angle = degrees(atan2(-z, xy_dist)) + degrees(acos(clamp(cos_femur, -1, 1)))

    # Convert to servo angles
    # LX-16A range is 0-240° (position 0-1000), center at 120° (position 500)
    coxa_servo = 120 + coxa_angle
    femur_servo = femur_angle + 30  # Offset for mechanical zero
    tibia_servo = 240 - tibia_angle  # Inverted

    # Clamp to valid range
    coxa_servo = clamp(coxa_servo, 0, 240)
    femur_servo = clamp(femur_servo, 0, 240)
    tibia_servo = clamp(tibia_servo, 0, 240)

    return coxa_servo, femur_servo, tibia_servo


# =============================================================================
# Hexapod Controller
# =============================================================================

class Hexapod:
    """
    Main hexapod robot controller.

    Controls 18 LX-16A servos (6 legs × 3 joints) with inverse kinematics.
    """

    def __init__(self, port: str = '/dev/serial0', config_file: str = 'config.json',
                 simulation: bool = False):
        """
        Initialize hexapod controller.

        Args:
            port: Serial port for LX-16A bus
            config_file: Path to configuration JSON file
            simulation: If True, run without hardware
        """
        self.simulation = simulation
        self.config_file = config_file

        # Initialize servo bus
        self.bus = LX16A(port=port, simulation=simulation)

        # Load configuration
        self.config = self._load_config()

        # Geometry from config or defaults
        self.coxa_len = self.config.get('geometry', {}).get('coxa_length', COXA_LENGTH)
        self.femur_len = self.config.get('geometry', {}).get('femur_length', FEMUR_LENGTH)
        self.tibia_len = self.config.get('geometry', {}).get('tibia_length', TIBIA_LENGTH)
        self.body_radius = self.config.get('geometry', {}).get('body_radius', BODY_RADIUS)

        # Servo mapping
        self.servo_ids = self.config.get('servo_ids', DEFAULT_SERVO_IDS)
        self.servo_dir = self.config.get('servo_directions', DEFAULT_SERVO_DIR)

        # Calibration offsets (position offset for each servo)
        self.calibration = self.config.get('calibration', {})

        # Body pose
        self.body_height = 80  # mm
        self.body_pitch = 0    # degrees
        self.body_roll = 0     # degrees
        self.body_yaw = 0      # degrees

        # Current leg positions (local coordinates)
        self.leg_positions: Dict[str, Tuple[float, float, float]] = {}
        self._reset_positions()

    def _load_config(self) -> dict:
        """Load configuration from JSON file."""
        if os.path.exists(self.config_file):
            try:
                with open(self.config_file, 'r') as f:
                    return json.load(f)
            except (json.JSONDecodeError, IOError) as e:
                print(f"Warning: Could not load config: {e}")
        return {}
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

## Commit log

2025-12-29 Initial commit: 3DOF hexapod walking robot
    - OpenSCAD parametric leg design (coxa, femur, tibia)
    - Python control software with inverse kinematics
    - Gait patterns: tripod, wave, ripple
    - PCA9685 PWM driver support (dual board)
    - Servo calibration tools
    - Hardware BOM and print queue tracking
    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
    [leg.scad, test_leg.scad]
2025-12-29 Update to use all SG90 servos (18x)
    - Remove HS-82MG requirement, use SG90 for coxa joints
    - Update CAD coxa_bracket module for SG90 dimensions
    - Update HARDWARE, PLAN.md, README.md, WIRING.md
    Note: Keep robot lightweight (<500g) for adequate torque
    [leg.scad]
2025-12-29 Add sensor array documentation for big hex
    - MPU6050 IMU for balance/orientation
    - VL53L0X ToF sensors (x3) for obstacle detection
    - Foot contact switches (x6) for terrain sensing
    - INA219 for power monitoring
    - Wiring diagrams and I2C address map
    - Python code examples
    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
2025-12-30 Fix multiple issues from deep code review
    High priority (reliability/safety):
    - Add I2C error handling with retry logic to PCA9685 driver
    - Fix PWM prescale calculation to match PCA9685 datasheet
    - Fix ripple gait concurrent modification bug
    Medium priority (correctness):
    - Fix calibration file path to use absolute path
    - Fix shallow copy of calibration defaults (use deepcopy)
    - Add coordinate system documentation to stand() method
    - Document I2C address conflict between INA219 and PCA9685
    - Fix GPIO pin documentation (2/3 not 0/1)
    Low priority (polish):
    - Add reset_positions() method to GaitController
    - Move math imports to module level in gait.py
    - Fix shutdown() to disable only used ser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
    [calibrate.py, gait.py, hexapod.py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]
2025-12-31 Add CAD files and servo control software for Big Hex
    CAD:
    - OpenSCAD parametric design (leg.scad) with corrected LX-16A dimensions
    - All STL files for 3D printing (body plates, legs, standoffs)
    - Body plate segmented for standard 220mm printers
    Software:
    - lx16a.py: LX-16A serial bus servo driver with simulation mode
    - hexapod.py: Main controller with inverse kinematics
    - gait.py: Tripod and wave gait patterns
    - calibrate.py: Interactive servo calibration tool
    - demo.py: Test and demo scripts
    - config.json: Robot configuration
    [leg.scad]
2026-01-02 Update hexapod design for ESP32 and MG90S servos
    - Switch from Pi Pico to ESP32 as main controller in wiring diagram
    - Update all pin mappings for ESP32 (I2C, UART, XSHUT)
    - Mark Pi Zero 2W as optional (for camera/vision only)
    - Increase servo clearance from 0.3mm to 0.4mm for MG90S compatibility
    - Add lightweight print profile (15% infill, 2 walls) for leg parts
    - Update print queue with individual test leg parts
    - Add PURCHASED file tracking ordered components
    [leg.scad]
2026-01-02 Fix code inconsistencies from final review
    - hexapod.py: Update docstring for ESP32 and MG90S servo mix
    - hexapod.py: Change default height from 50mm to 40mm (MG90S torque)
    - pca9685.py: Fix fallback I2C pins for ESP32 (GPIO21/22)
    - pico_main.py: Add deprecation notice, point to esp32_main.py
    [hexapod.py, pca9685.py, pico_main.py]
2026-01-02 Add STL exports for 3D printing
    - export_parts.scad: Wrapper script for exporting individual parts
    - STL files: coxa_bracket, femur_link, tibia_link, foot_tip, body_segment
    [body_segment.stl, coxa_bracket.stl, export_parts.scad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]
2026-01-02 Update print queue for JLC3DP order
    - Order 34 parts (27 PLA + 7 TPU) from JLC3DP
    - Include 1 spare per leg part type
    - Estimated cost: ~$55-60 shipped
    - Timeline: ~2-3 weeks
